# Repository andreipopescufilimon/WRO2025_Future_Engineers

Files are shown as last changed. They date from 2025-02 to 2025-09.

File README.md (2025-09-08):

# WRO2025 Future Engineers – Nerdvana Taurus Team

---

## WRO Open Championship 2025, Slovenia

At WRO Open 2025 in Slovenia, things started off really well for us. In the Open Round Challenge we managed to get full points in just 24 seconds, the fastest time there. Before that, in practice, the robot was running smoothly through all the tests and random cases we tried. At some point it had some strange speed drops, which we thought were from a bad cable connection. We resoldered everything, and from then on it worked perfectly again. Then came the real chaos. Just five minutes before the first official Obstacle Round, our motor driver chip blew up with a small spark. We tried to swap it out, but there just wasn’t enough time. The result: 0 points. Not exactly how we imagined the round going. That afternoon we stayed and worked on the robot, replacing the broken chip and all the resistors and capacitors around it. The next day, during the two hours of practice, the robot was back on track and almost hit full points again, but with small inconsistencies on the parking alignment. In the official run though, it made a small drift when doing the parking, and touched the parking wall, and because of the rules the whole parking didn’t count—not even partially. That was a bit painful, but in the end we still took 2nd place overall, and on documentation we scored 28 points. So yeah, it was a mix of highs and lows: fastest run of the round, a blown motor driver, afternoon repairs, and a nearly perfect comeback.

Thanks to HyperLine Robotics for sponsoring us! 

---

Repository of Nerdvana Taurus Team competing in the **World Robot Olympiad (WRO) 2025**, Future Engineers category. 

---

## 📚 Table of Contents

- [👥 The Team](#the-team)
- [🎯 Challenge Overview](#challenge-overview)
- [🤖 Our Robot](#our-robot)
- [⚙️ Mobility Management](#mobility-management)
  - [🚗 Drivebase](#drivebase)
    - [🔧 Drivetrain](#drivetrain)
    - [⚙️ Motor](#motor)
    - [🛞 Wheels](#wheels)
    - [🔌 Motor Driver IFX9201SG](#motor-driver)
    - [🌪️ Impeller](#impeller)
  - [🔄 Steering](#steering)
    - [🔄 Steering Servo Motor](#servo-motor)
  - [🏎️ Chassis & Component Mounting](#chassis)
    - [✨ Key Features & Advantages](#key-features)
    - [🔧 Assembly Process](#assembly-process)
      - [🔧 Assembly Process Video](#assembly-process-video)
      - [🔧 3D print the parts](#3d-print-the-parts)
      - [🔧 Assemble the robot](#assembly)
- [🛠️ Power and Sense Management](#power-and-sense-management)
  - [🔋 Li-Po Battery](#li-po-battery)
  - [🖥️ Arduino Nano ESP32](#arduino-nano-esp32)
  - [🧭 IMU Sensor BMI088](#imu-sensor-bmi088)
  - [📷 OpenMV H7 Camera](#openmv-h7-camera)
  - [⚙️ Drive Motor](#drive-motor)
  - [⚙️ Motor Driver IFX9201SG](#motor-driver)
  - [🔄 Steering Servo MG90S](#steering-servo)
  - [⚙️ Impeller](#impeller)
  - [📏 Pololu PWM Distance Sensor](#distance-sensors)
  - [🔌 Voltage Regulator D24V50F5](#voltage-regulator)
  - [🛠️ PCB Design](#pcb-design)
  - [⚡ Power Consumption](#power-consumption)
- [💻 Components coding](#components-coding)
  - [⚡ Drive motor](#drive-motor-coding)
  - [🌪️ Impeller](#impeller-coding)
  - [🎮 Servo motor](#servo-motor-coding)
  - [🧭 IMU](#imu-coding)
  - [📡 Distance sensors](#distance-sensors-coding)
  - [📷 Camera](#camera-coding)
- [📝 Obstacle Management](#obstacle-management)
  - [🏁 Open Round](#open-round) 
  - [⚡ Final Round](#final-round)
  - [🅿️ Start from Parking](#start-from-parking)
  - [🅿️ Parking](#parking)
- [📽️ Performance Video](#performance-video)
- [💰 Cost Analysis](#cost-analysis)
  - [📦 Component Costs](#components-costs)
  - [🔌 PCB Manufacturing Cost](#pcb-cost)
  - [🖨️ 3D Printing Cost](#3d-printing-cost)
  - [🔩 Other Materials (Screws, Nuts, Miscellaneous)](#other-materials-cost)
  - [💵 Total Cost](#total-cost)
- [📂 Resources](#resources)
- [📜 License](#license)

## 📂 Folder Structure

This repository is organized as follows:

```
📦 WRO2025_Future_Engineers
├── 📁 3D-models             # Contains 3D design files for the robot's components
│   ├── 📁 old-3D-models     # Previous versions of 3D models
│   └── 📁 step-models       # 3D models in STEP format
├── 📁 electrical-schematics # Circuit diagrams and wiring
├── 📁 github-commits        # Commit logs and change tracking details for this repository
├── 📁 media                 # Images and videos 
│   ├── 📁 robot-photos      # Photos of the robot
│   ├── 📁 team-photos       # Pictures of team members and teamwork
│   └── 📁 video             # Recorded testing
├── 📁 other                 # Contains files that do not fit into other categories
├── 📁 src                   # Main source code for the robot
├── 📁 technical-draws       # Technical drawings and mechanical blueprints
├── 📁 video                 # Videos of our robot
├── 📄 LICENSE               # MIT License for the project
└── 📄 README.md             # Main documentation for the project
```

---

## 👥 The Team 

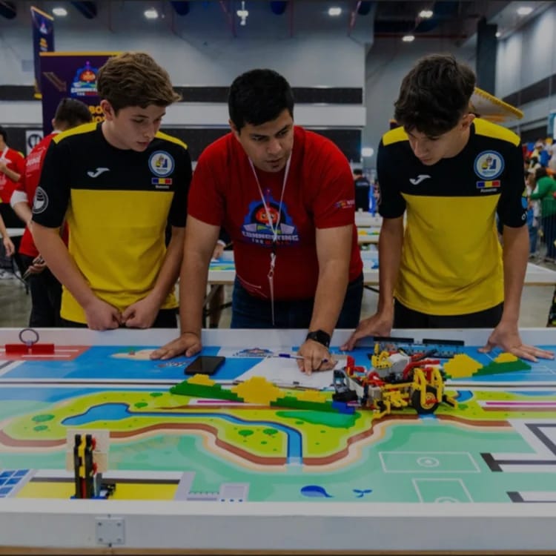
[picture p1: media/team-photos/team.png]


**This image was taken at the **WRO 2023 International Final** in Panama, where we placed **14th in the Robomission Junior Category**.*

### **Popescu Filimon Andrei Cosmin** (Left Side)
**Age:** 17 <br>

**High School:** International Computer High School Bucharest (ICHB)  

**Description:**  
Hi! I’m Andrei from Romania, and this is my fifth WRO season. This is my first season in Future Engineers, as before I competed in Robomission category. I am passionate about robotics especially electronics and latest algorithms and tech. Over the years, I have worked on multiple robotics projects, including line followers, sumo bots, and air quality modules. Apart from robotics, I also enjoy cybersecurity, programming, and cycling.

---

### **Horia Simion** (Right Side)
**Age:** 16 <br>
**High School:** National College "Mihai Viteazul" (CNMV)

**Description:**  
Hi! I’m Horia from Romania, and this is my second WRO season competing alongside Andrei. I have participated in RoboMission multiple times, gaining valuable experience in solving various problems that may arise while building a robot. I have a strong interest in technology and robotics and am always eager to learn and experiment with new ideas.

---

## 🎯 Challenge Overview 

The **WRO 2025 Future Engineers** challenge pushes teams to develop a **fully autonomous vehicle** capable of navigating a **dynamic and randomized racetrack** using **sensors, computer vision, and advanced control algorithms**. The goal is to complete **multiple laps** while adapting to randomized obstacles, following **strict driving rules**, and successfully executing a **parallel parking maneuver** at the end of the course.

### 📌 Competition Format 

- **🏁 Open Challenge**: The vehicle must complete **three (3) laps** on a track with **randomly placed inside walls**.

- **🚦 Obstacle Challenge**: The vehicle must complete **three (3) laps** while detecting and responding to **randomly placed red and green traffic signs**:
  - 🟥 **Red markers** ➜ The vehicle must stay on the **right side of the lane**.
  - 🟩 **Green markers** ➜ The vehicle must stay on the **left side of the lane**.
  
  After completing the three laps, the vehicle must **locate the designated parking zone** and perform a **precise parallel parking maneuver** within a limited space, adding an extra layer of difficulty.
  
- **📑 Documentation**: Each team must maintain a **public GitHub repository** showcasing their **engineering process, vehicle design, and source code**.

### 🏆 Scoring & Evaluation
Scoring is based on **accuracy, technical documentation and speed**, rewarding teams that balance **efficiency, adaptability, and innovation**. This challenge not only tests **robotics and programming skills** but also promotes **problem-solving, teamwork, and engineering creativity**.

🔗 **Find out more about the challenge [here](https://wro-association.org/wp-content/uploads/WRO-2025-Future-Engineers-Self-Driving-Cars-General-Rules.pdf).** 🚀

---

## 🤖 Our Robot 
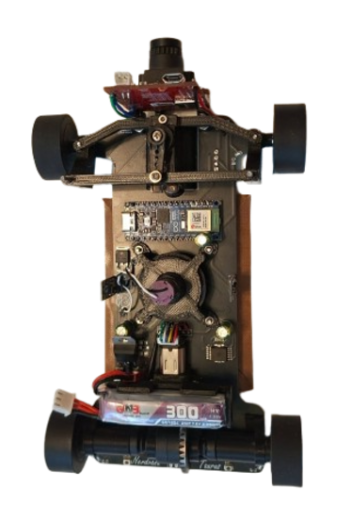
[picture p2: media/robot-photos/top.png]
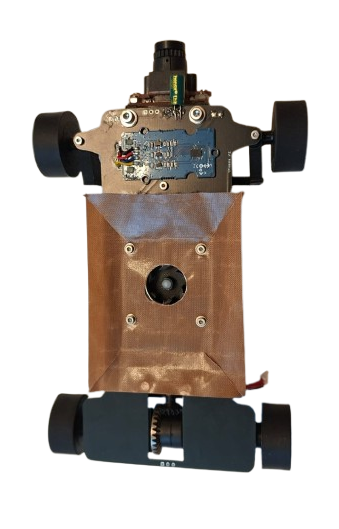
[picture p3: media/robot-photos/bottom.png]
|  |  |
|---|---|
| <p align="center"><b>Top</b></p> | <p align="center"><b>Bottom</b></p> |

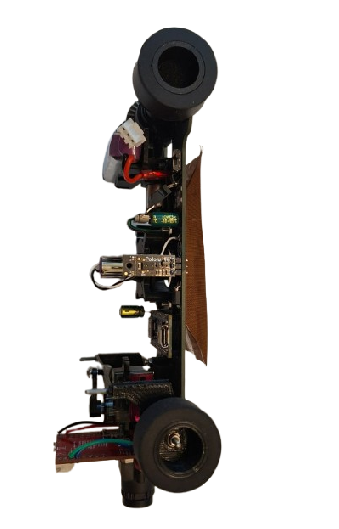
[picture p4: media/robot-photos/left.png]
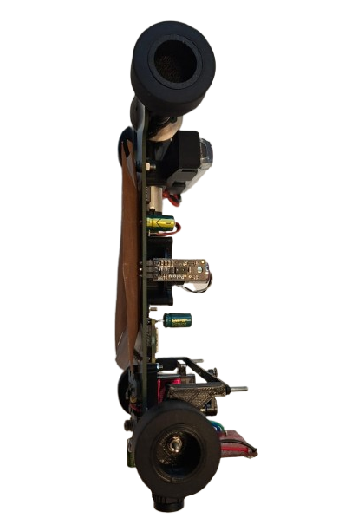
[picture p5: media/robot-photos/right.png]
|  |  |
|---|---|
| <p align="center"><b>Left</b></p> | <p align="center"><b>Right</b></p> |

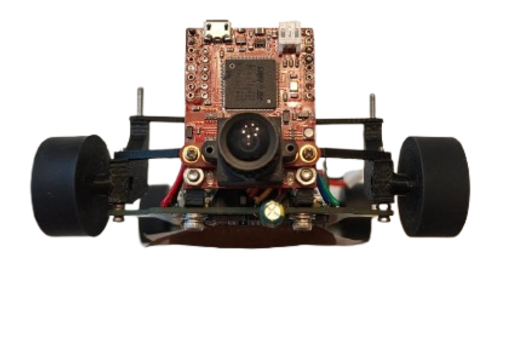
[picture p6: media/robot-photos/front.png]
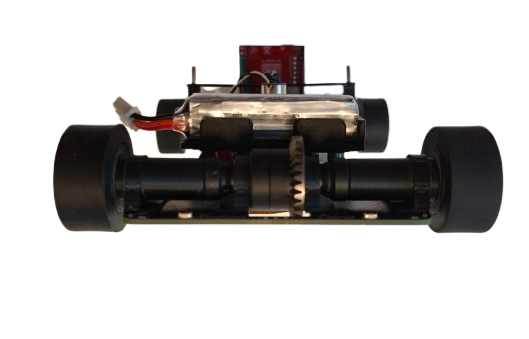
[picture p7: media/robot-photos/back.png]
|  |  |
|---|---|
| <p align="center"><b>Front</b></p> | <p align="center"><b>Back</b></p> |

---

## 🚗 Mobility Management 

The robot's mobility is controlled through **a fully PCB chassis, a servo-based steering system, and a drivetrain featuring a RC differential and axes**. These components work together to ensure smooth, **precise movement with optimized traction, stability, and efficient power management**.

## ⚙️ **Drivebase** 

### 🔧 **Drivetrain** 

The drivetrain uses a sealed RC differential at the rear, driven by a **Pololu 30:1 HPCB micro gearmotor** through a **3D printed pinion** → **differential input gear**. The motor is held in a 3D-printed support with the battery mounted above, keeping the center of mass centered and low. Rear outputs rotate in bearings seated inside 4 printed rings that are super-glued to the PCB chassis, minimizing friction and parts count.
At the front, the wheels are fully 3D-printed and each wheel runs on two bearings (inner + outer) for a rigid, wobble-free hub that steers precisely.

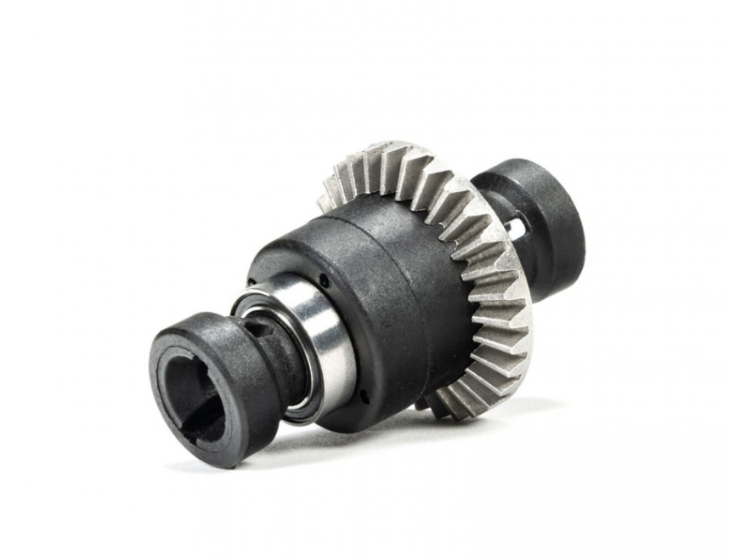
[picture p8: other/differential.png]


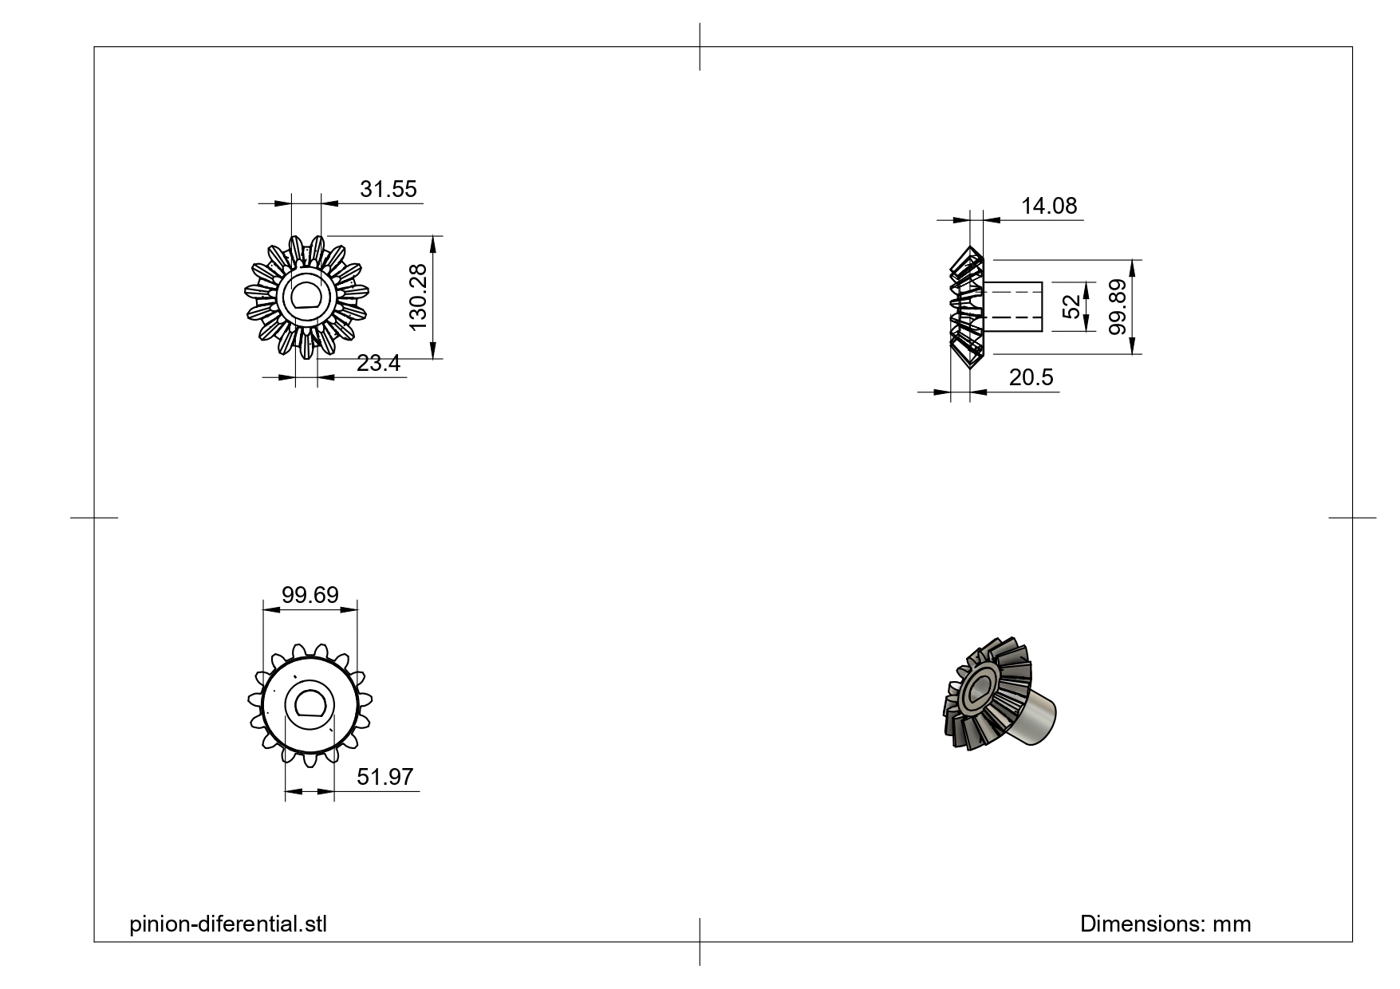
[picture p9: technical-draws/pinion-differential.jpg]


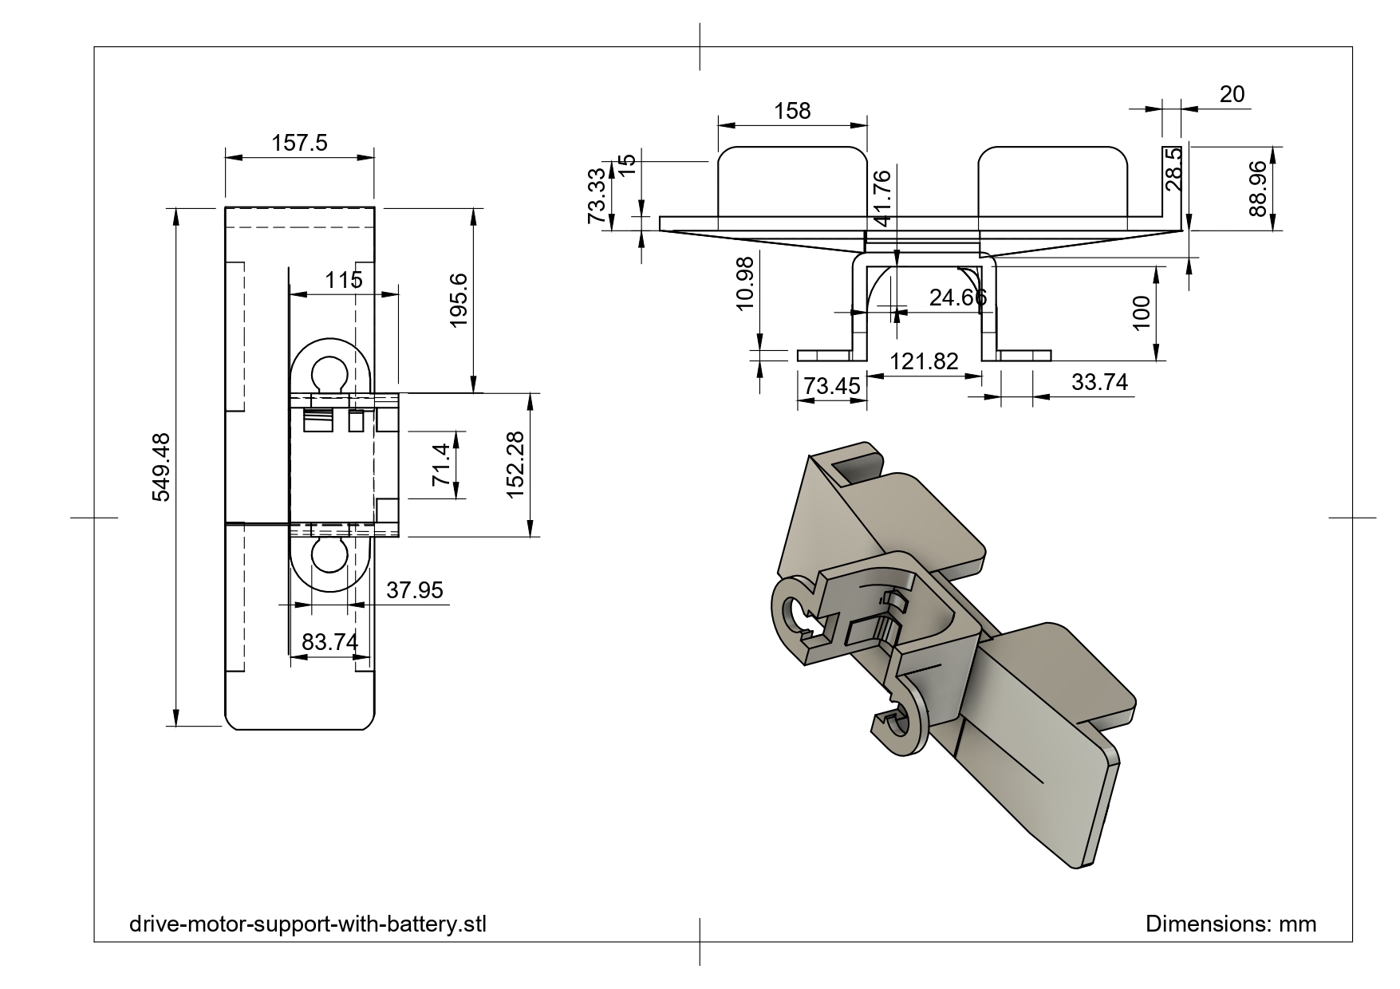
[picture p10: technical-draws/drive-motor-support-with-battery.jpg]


To maximize grip on the track without adding mass, we use a **downforce impeller (1020 coreless motor)** that pulls air from under the robot, increasing the normal force. The impeller is PWM-controlled via an **RFR3411 MOSFET (low-side switch)**. The drive motor is controlled by an **IFX9201SG driver (PWM + DIR)** with an active brake pulse for precise stopping, while the encoder on the gearmotor provides odometry for short, accurate moves (e.g., avoidance hops, parking nudges).

### ⚙️ **Motor – 30:1 Micro Metal Pololu Gearmotor HPCB** 
Following past testing, we selected **a high-power 30:1 Micro Metal Gearmotor (12V)** for the drive system. This motor provides an **optimal balance of speed and torque**, allowing the robot to maintain stability while navigating turns.

|  | **Specifications** |
|---|---|
| **Model:** 30:1 HPCB | **Voltage:** 6V |
| **No-load Speed:** 1000 RPM | **No-load Current:** 120mA |
| **Stall Torque:** ~0.4 kg·cm | **Stall Current:** 1.6A |
| 🔗 **[Buy Here](https://www.pololu.com/product/3038)** | **Function:** Drives the robot |

**Why We Chose This Motor?**  
**- Gear ratio provides suffi cient torque** without sacrificing efficiency.  
**- Compact and lightweight design**, allowing integration into a lightweight robot.  

### 🛞 Wheels & Tires (Silicone) 

Our robot uses cast silicone tires on 3D-printed hubs. Silicone provides high, repeatable static friction on painted boards and vinyl, which pairs perfectly with the rear differential and downforce impeller—more grip when we need it, without adding mass.

**Why silicone?**
- Grip & consistency: Strong adhesion on smooth surfaces → faster exits and shorter braking distances.
- Low wear on the map: Softer compound grips without scratching.
- Stable handling: Predictable breakaway, so PD/PID steering stays smooth.

**Construction:**
- Rims: 3D-printed hubs with dual bearings (inner + outer) for a rigid, wobble-free wheel.
- Tire: Cast silicone ring fitted onto a mechanical bead on the rim (no harsh solvents needed).
- Fit: Rear wheels mount directly to the diff outputs; fronts ride on steering hubs for low friction.

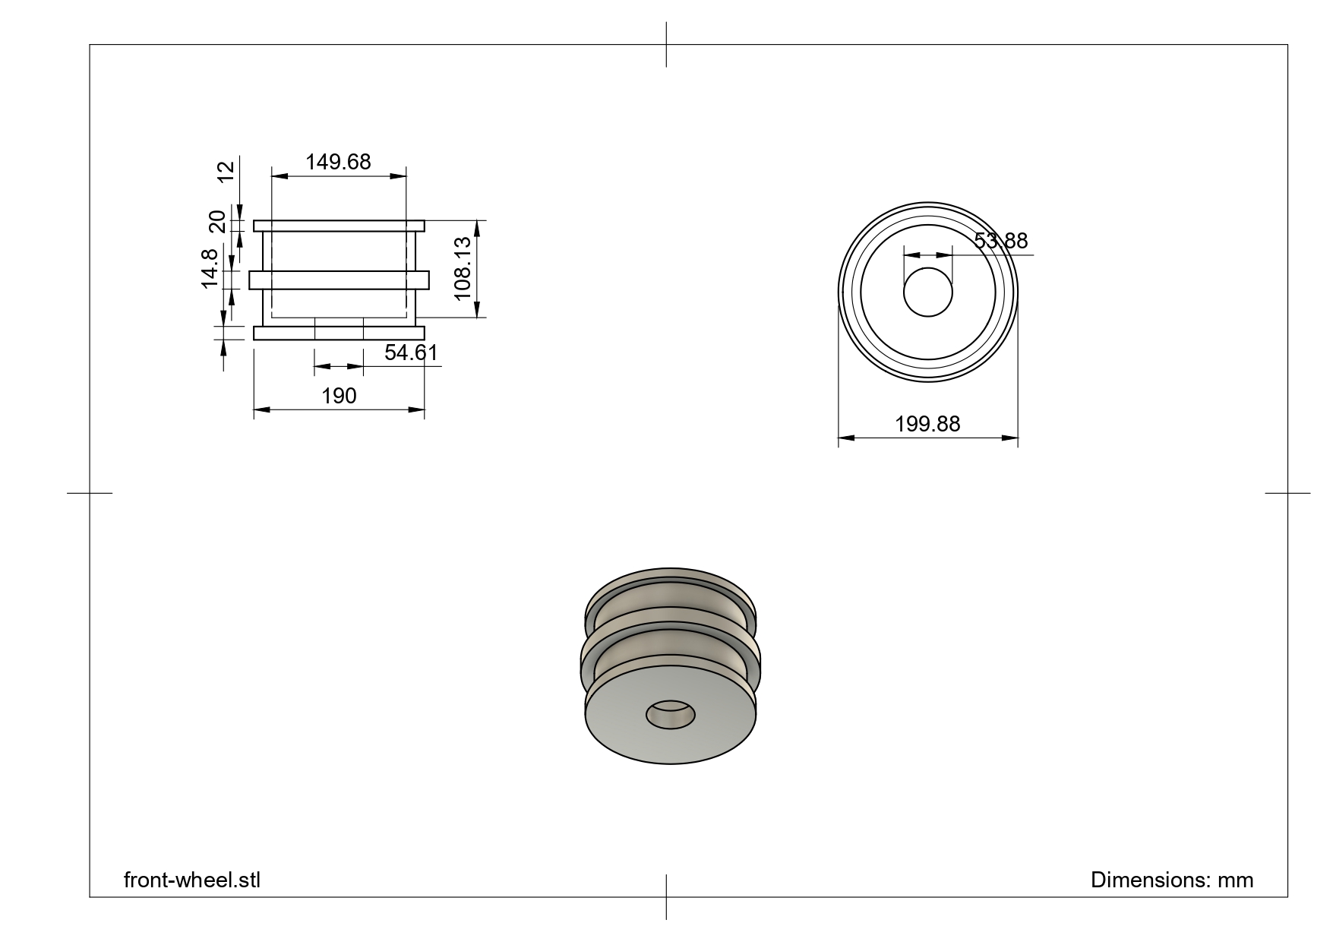
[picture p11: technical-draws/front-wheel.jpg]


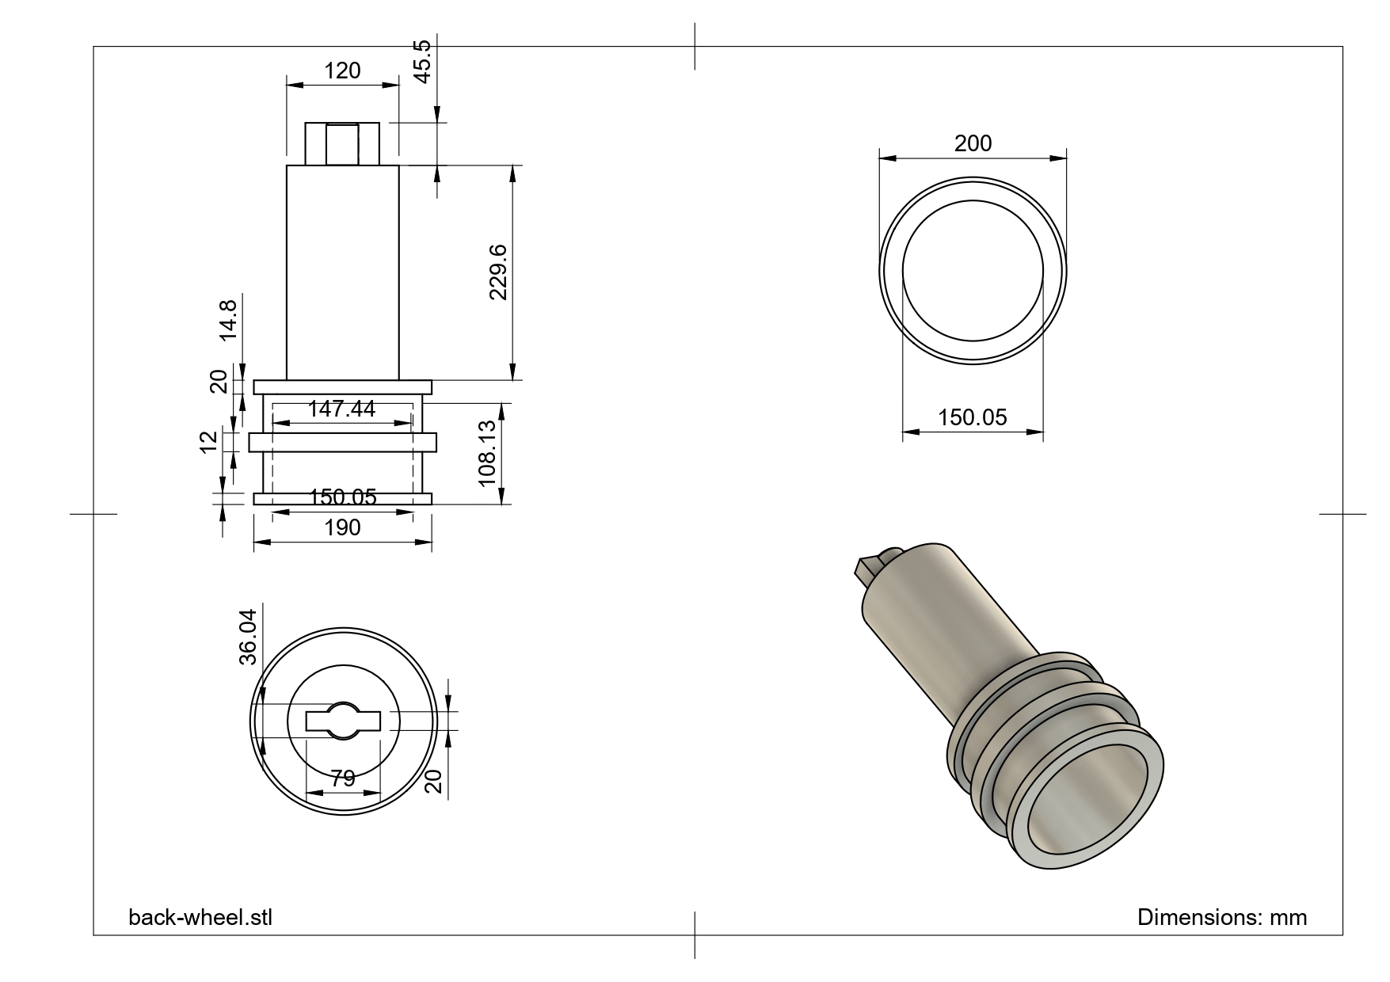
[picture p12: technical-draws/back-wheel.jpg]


### 🔌 **IFX9201SG Motor Driver** 

The **IFX9201SG** motor driver is used to control the robot’s high-performance drive or impeller motor with precision and efficiency. It supports PWM-based speed control and direction control while integrating advanced protection features, making it ideal for demanding robotics applications. The IFX9201SG is directly integrated into our PCB, ensuring compact design and reliable communication with the Arduino Nano ESP32.

|  | **Specifications** |
|---|---|
| **Model:** IFX9201SG | **Operating Voltage:** 5.5V – 45V |
| **Logic Voltage:** 3.3V / 5V compatible | **PWM Frequency:** Up to 20 kHz |
| **Max Continuous Current:** 5A | **Max Peak Current:** 8A per channel |
| **Control Interface:** PWM + Direction pins | **Built-in Protections:** Overtemperature, Overcurrent, Undervoltage, Short-to-GND/Battery |
| 🔗 **[Buy Here](https://www.lcsc.com/product-image/C112633.html)** | **Function:** Controls drive motors |

### **⚙️ Impeller for downforce** <a id="impeller">

The **impeller** generates downforce to improve the robot’s grip on the track at high speeds. Powered by a **1020 coreless DC motor**, it delivers extremely high RPM with minimal weight, making it ideal for competitive line follower and robotracer builds. Its low rotor inertia ensures instant acceleration, while the compact size allows for easy integration.

|  | **Specifications** |
|---|---|
| **Type:** Coreless DC Motor | **Model:** 1020 |
| **Voltage:** 3.7–7.4V | **Shaft Diameter:** 1.0mm |
| **No-Load Speed:** ~53,000 RPM @ 3.7V	 | **	Weight:** ~4.5g |
| **Current Draw (Avg):** ~1A @ 3.7V	 | **Peak Current:** ~2.5A |
| 🔗 **[Buy Here](https://hyperlinerobotics.com/products/impeller.html)** | **Function:** Drives the downforce impeller |

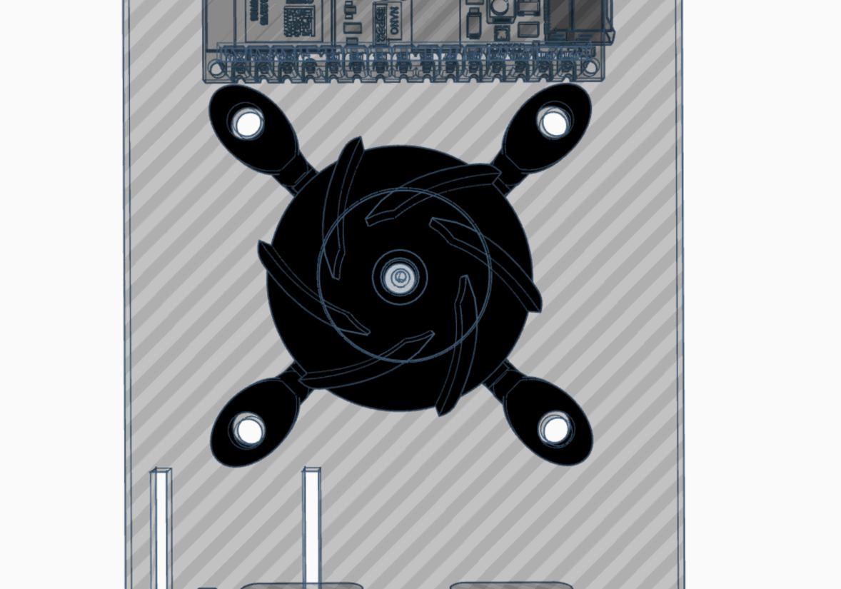
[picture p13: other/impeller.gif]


---

## 🔄 **Steering** 

The **steering system** is a critical part of the robot, ensuring precise maneuverability and smooth turns. Our design is based on a **parallelogram steering mechanism**, where both front wheels turn at the same angle through a single servo-controlled linkage. This setup provides predictable and stable steering, making it easy to use for an autonomous vehicle. Instead of using an **Ackermann steering system**, which requires more complex calculations and linkages, we opted for a **simpler and more lightweight solution** that offers consistent control. Our steering system allows for a maximum turning angle of 80 degrees in both the left and right directions. This range provides precise maneuverability, enabling the robot to navigate sharp turns efficiently while maintaining stability.

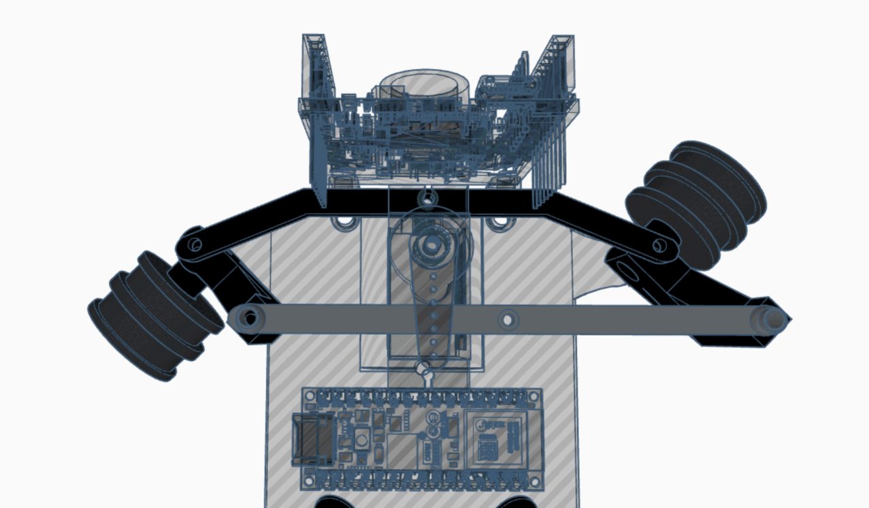
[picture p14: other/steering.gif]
Demo GIF


Our **steering arm is directly connected to the servo**, which moves the two front wheels simultaneously. This ensures that the turning response is immediate and proportional to the servo's motion. The **wheels are mounted on special mounts hubs**, allowing for smooth and precise movement without excessive friction. To ensure **structural integrity and long-term reliability**, the steering system is **assembled using 2 M2 screws on which the hubs can turn**. 

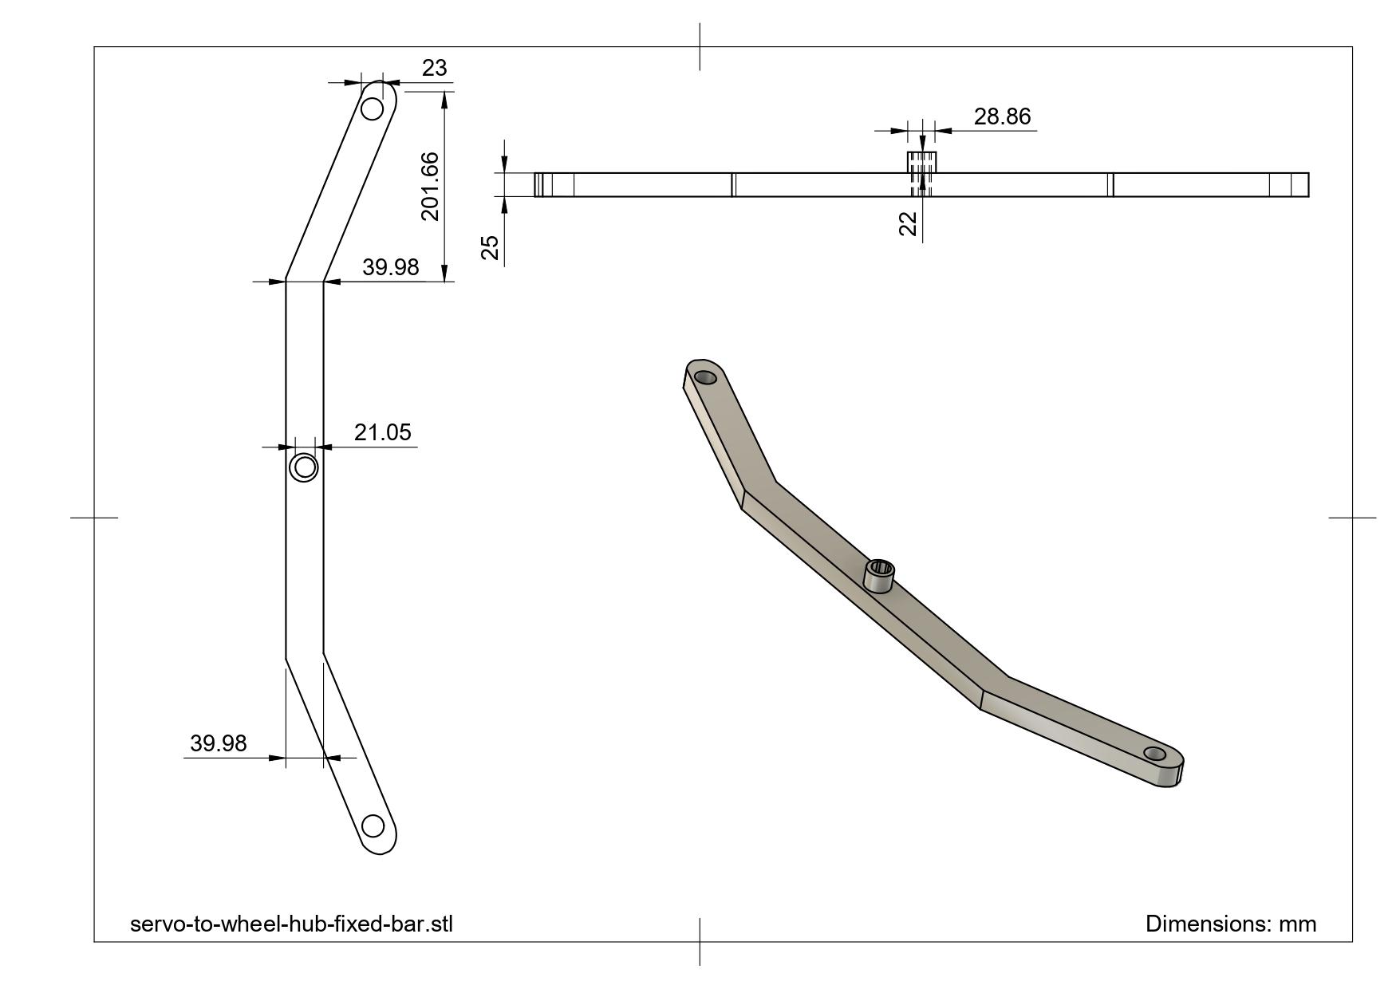
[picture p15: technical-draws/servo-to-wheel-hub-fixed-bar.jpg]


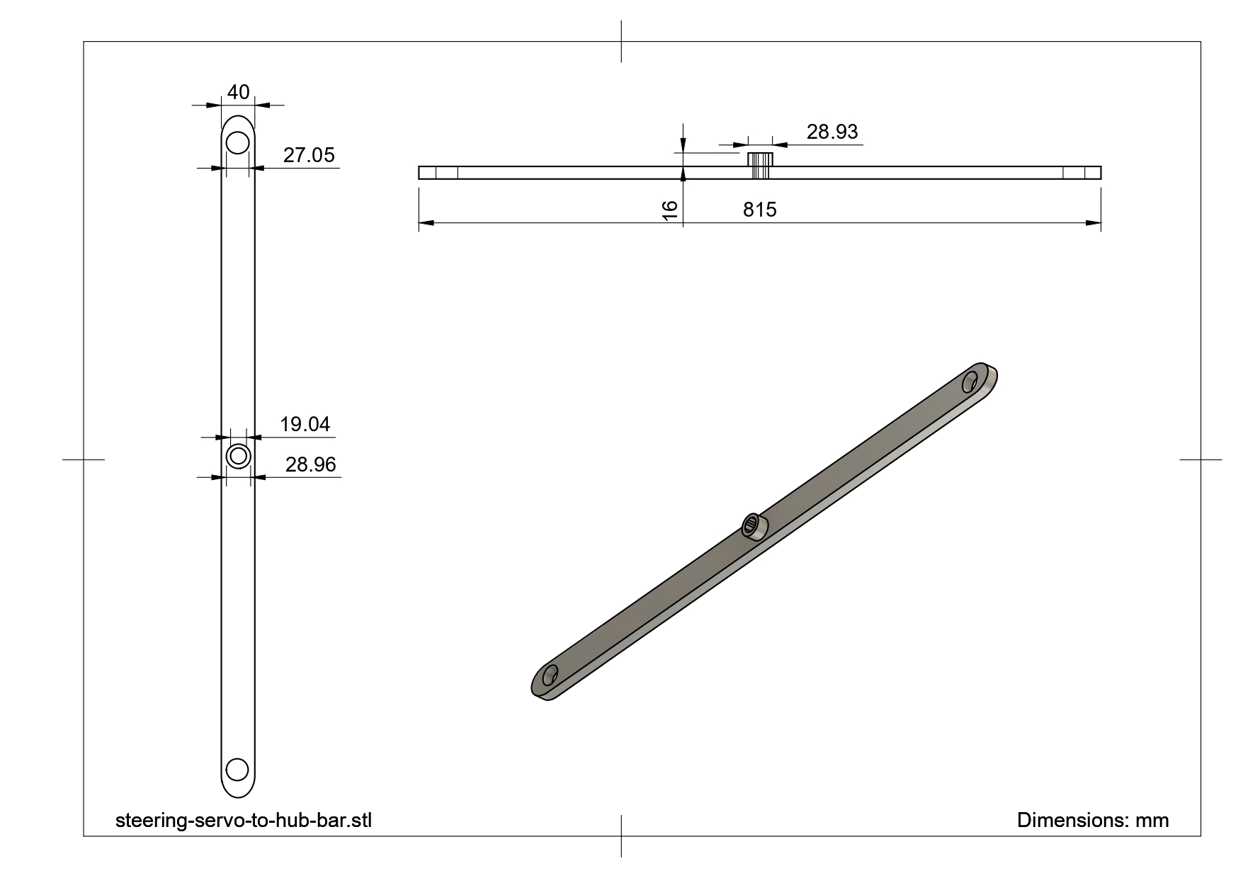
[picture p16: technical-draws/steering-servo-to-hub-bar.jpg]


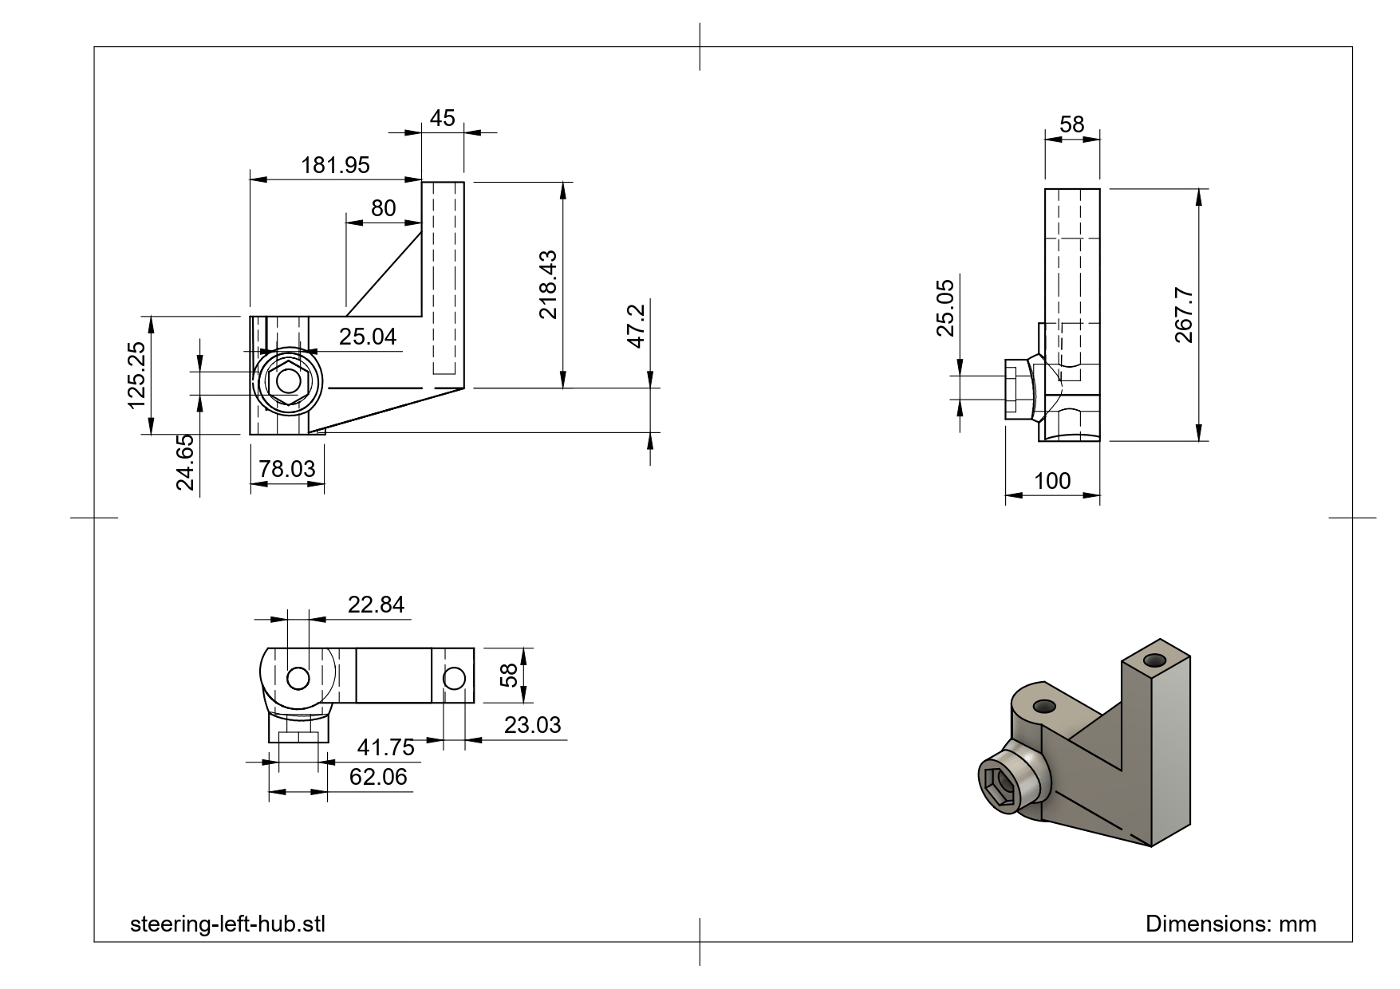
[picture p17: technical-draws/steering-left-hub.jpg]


**⚙️ Design Considerations & Improvements** <br>
While the parallelogram steering system is effective, some potential enhancements could improve its performance. Additionally, optimizing the **motor mounts** could reduce mechanical play, making the system more precise. In future iterations, we may experiment with **Ackermann geometry** and suspension to better distribute wheel angles during turns, further improving efficiency and reducing tire slippage.

---

### **🔄 Steering Servo – MG90S** 

To control the steering system, we use an **MG90S micro servo**, known for its high torque and fast response. This servo enables quick and precise adjustments while maintaining a compact and lightweight design. Featuring **metal gears**, it ensures durability and reliability over extended use. The servo is securely mounted onto the chassis with two screws, and the steering arm is directly attached to its output shaft, providing smooth and efficient motion transfer for accurate steering.

|  | **Specifications** |
|---|---|
| **Model:** MG90S | **Voltage:** 5V |
| **Torque:** 2.2kg/cm | **Signal Type:** PWM |
| **Current Draw (Avg):** 120mA | **Peak Current:** 500mA |
| **Weight:** ~13.4g | **Gears:** Plastic |
| 🔗 **[Buy Here](https://www.optimusdigital.ro/ro/motoare-servomotoare/271-servomotor-mg90s.html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)** | **Function:** Controls steering |

---

## 🏎️ **Chassis & Component Mounting** 

At the national stage, we used a **fully 3D-printed chassis**, which allowed us to quickly prototype a compact and optimized structure. However, for the current version, we upgraded to a **PCB-based chassis**. This not only reduces weight further but also integrates electronics directly into the structure, making the robot lighter, cleaner, and more reliable.

The robot is driven by **a single high-performance motor**, which is connected to a **professional RC differential**. This setup allows reducing complexity while maintaining precise control over movement.

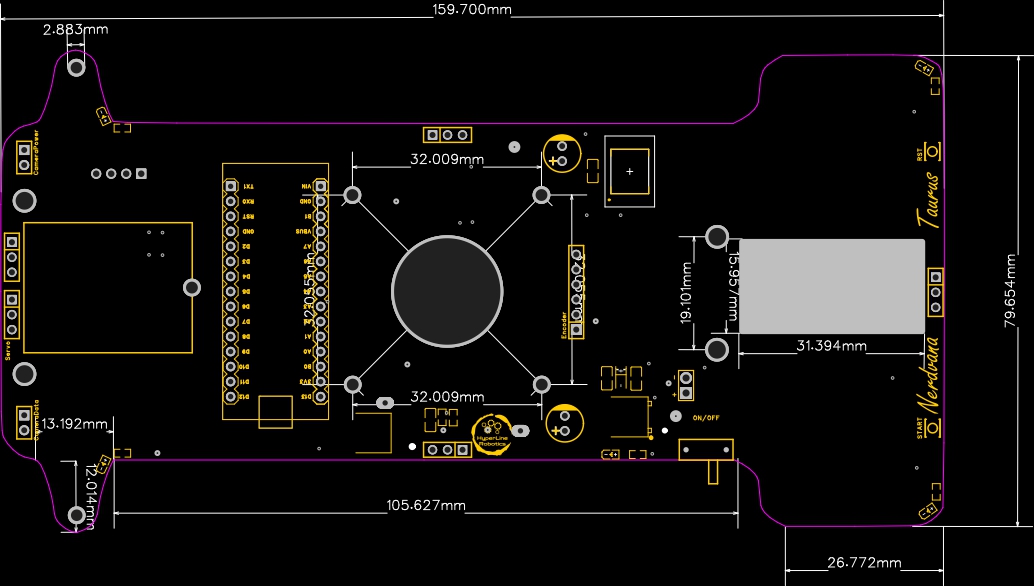
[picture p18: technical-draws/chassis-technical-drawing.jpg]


**Key Features & Advantages** 

➜ **Lightweight & Durable** – The **PCB chassis** ensures a strong lightweight structure, optimizing performance.  
➜ **Balanced Design** – The **battery is centrally placed on top of the motor**, ensuring even weight distribution and stability. Meanwhile we use a high power impeller that sucks the air under the robot and create an artificial downforce effect over the robot maintaining its grip.  
➜ **Easy Component Mounting** – Pre-designed slots for **motor, steering servo, and camera** make assembly quick and efficient.  
➜ **Organized Wiring & Cable Management**  
&nbsp; &nbsp; 🔹 **Integrated PCB routing** eliminates unnecessary wiring, ensuring a cleaner and more reliable setup.  
&nbsp; &nbsp; 🔹 **Super glue secures servo and other tiny parts**, keeping each part in its place even after longer runs. 

---

## 🔧 Assembly Process 

🔗 **[Click here to watch the assembly video on YouTube](https://youtu.be/sC2x8HgDEvk)** 

### 1: 3D Print the Parts 

The 3D model files are available in the [`/3D-models`](https://github.com/andreipopescufilimon/WRO2025_Future_Engineers/tree/main/3D-models) folder. We used a **BambuLab X1-Carbon**, but any good quality printer will work.

Printed components include:

* **Servo base** – for securing the MG90S steering servo.
* **Camera mount (90° bracket)** – to hold the camera in position.
* **Motor support** – for fixing the drive motor with M3 screws.
* **Bearing rings** – 4 small rings to be glued on the PCB chassis for smooth differential rotation.
* **Front wheels** – fully 3D-printed, each equipped with **2 bearings (inner + outer)** for stable and secured placement.

---

### 2: Assemble the Chassis & Components 

The final robot is built on a **custom PCB chassis**, manufactured by **JLCPCB**, which acts as both the **structural base** and the **mainboard for electronics**.

#### 🔧 **Main Assembly Steps**

1. **PCB Preparation**

   * Order the chassis PCB from **JLCPCB**.
   * Solder the **Arduino Nano ESP32** into its slot.
   * Solder the **4 distance sensors** with **90° male pins**, positioned on all four sides of the robot.

2. **Steering System**

   * Mount the **MG90S servo** on the **3D-printed base**, then super glue the base securely to the PCB chassis.
   * Fix the **steering hubs** (left & right) on **M2 screws**, allowing smooth wheel hub rotation.
   * Connect the **servo arm to the steering hubs** using **two metal link bars** for precise steering.
   * Install the **3D-printed front wheels**, each fitted with **dual bearings (inner + outer)** for reliable and stable rotation.

3. **Camera Mounting**

   * Attach the camera using the **90° 3D-printed bracket**.
   * Secure it with **2 screws to the chassis** and **2 screws for the camera itself**.

4. **Motor & Drivetrain**

   * Place the **drive motor** on the **3D-printed support**, fixed with **2 × M3 screws**.
   * Secure the **impeller** with **4 screws** to its mounting position.
   * Assemble the **RC differential** with the rear wheels mounts that directly fit the differential left and right mounting holes.
   * Glue **4 printed rings** on the PCB chassis to house bearings, ensuring **smooth rear wheel rotation**.

5. **Wiring & Final Connections**

   * Solder all cables (servo, camera, motor encoder, impeller) to their designated pads on the PCB.
   * Use minimal hot glue to fix loose wires and prevent interference during movement.

---

## 🛠️ Power and Sense Management 

The robot's **power and sensing system** is designed for **efficiency, precision, and adaptability**. It consists of an **Arduino Nano ESP32, a Li-Po battery, BMI088 IMU, OpenMV H7 Camera, motors(drive motor and servo motor), and a voltage regulator**, all working together to ensure **stable operation and accurate navigation**.  

Each component has been carefully selected to provide **optimal performance**, minimize power consumption, and ensure **reliability in competition environments**.

---

### **🔋 Li-Po Battery – 2S 300mAh** 

The **Li-Po battery** provides a **compact, lightweight, and high-discharge** power source, making it ideal for our robot. The **7.4V output** is suitable for running our **motors and voltage regulator**, ensuring stable power delivery.

|  | **Specifications** |
|---|---|
| **Model:** 2S Li-Po | **Capacity:** 300mAh |
| **Voltage:** 7.4V | **Discharge Rate:** 60C |
| **Weight:** 12g | **Size:** 13.8 x 12 x 52.5mm |
| **Output Current:** Varies by load | **Connector Type:** JST |
| 🔗 **[Buy Here](https://www.jsumo.com/jsumo-3s-111-volt-450-mah-lipo-battery)** | **Function:** Powers the entire robot |

---

### **🖥️ Arduino Nano ESP32 – Main Controller** <a id="arduino-nano-esp32">

The **Arduino Nano ESP32** provides **high-speed processing, built-in Wi-Fi and Bluetooth, and extensive GPIO capabilities** in a **compact form**. This allows it to handle **sensor data, motor control, and vision processing efficiently**.

|  | **Specifications** |
|---|---|
| **Microcontroller:** ESP32 | **Flash Memory:** 4MB |
| **SRAM:** 520KB | **Frequency:** 240MHz |
| **Pins:** 22 | **Input Voltage:** 5V |
| **Current Draw (Avg):** 200mA | **Peak Current:** 500mA |
| 🔗 **[Buy Here](https://store.arduino.cc/en-ro/products/nano-esp32)** | **Function:** Controls all robot components |

---

### 🧭 IMU Sensor – BMI088 

The **BMI088 IMU** is used to **measure the robot's angular velocity and acceleration**, helping it maintain **stability and precise movement control**. It is essential for **calculating turns and avoiding drift**.

|  | **Specifications** |
|---|---|
| **Gyroscope Range:** ±2000°/s | **Accelerometer Range:** ±24g |
| **Interface:** I2C / SPI | **Supply Voltage:** 3.0V – 3.6V |
| **Current Draw:** ~3.2mA | **Weight:** ~1g |
| 🔗 [Buy Here](https://wiki.seeedstudio.com/Grove-6-Axis_Accelerometer&Gyroscope_BMI088/) | **Function:** Tracks orientation & motion |

---

### **📷 OpenMV H7 Camera – Vision Processing** <a id="openmv-h7-camera">

The **OpenMV H7 Camera** processes **traffic signs, lane detection, and other visual cues** in real-time. Unlike traditional cameras, it has a **built-in microcontroller**, reducing the processing load on the Arduino and allowing it to **focus on movement control**.

|  | **Specifications** |
|---|---|
| **Microcontroller:** STM32H7 | **Flash Memory:** 32MB |
| **RAM:** 512KB | **Frequency:** 480MHz |
| **Resolution:** 640x480 | **Frame Rate:** 60fps |
| **Current Draw (Avg):** 300mA | **Peak Current:** 400mA |
| 🔗 **[Buy Here](https://openmv.io/products/openmv-cam-h7)** | **Function:** Detects traffic signs & lanes |

---

### **⚙️ Drive Motor – 30:1 Micro Metal Gearmotor HPCB 6V w/ Encoder** <a id="drive-motor">

The **drive motor is responsible for propelling the robot forward**. The **30:1 gearbox** provides an excellent **balance of speed and torque**, while the **built-in encoder** allows for **precise speed control**.

|  | **Specifications** |
|---|---|
| **Type:** Micro Metal Gearmotor | **Gear Ratio:** 30:1 |
| **Voltage:** 6V | **Encoder:** Yes |
| **Current Draw (Avg):** 120mA | **Peak Current:** 1.6A |
| **Weight:** ~10g | **Shaft Diameter:** 3mm |
| 🔗 **[Buy Here](https://www.pololu.com/product/3038)** | **Function:** Drives the robot |

---

### **⚙️ IFX9201SG Motor Driver** 

The **IFX9201SG** motor driver is used to control the robot’s high-performance drive or impeller motor with precision and efficiency. It supports PWM-based speed control and direction control while integrating advanced protection features, making it ideal for demanding robotics applications. The IFX9201SG is directly integrated into our PCB, ensuring compact design and reliable communication with the Arduino Nano ESP32.

|  | **Specifications** |
|---|---|
| **Model:** IFX9201SG | **Operating Voltage:** 5.5V – 45V |
| **Logic Voltage:** 3.3V / 5V compatible | **PWM Frequency:** Up to 20 kHz |
| **Max Continuous Current:** 5A | **Max Peak Current:** 8A per channel |
| **Control Interface:** PWM + Direction pins | **Built-in Protections:** Overtemperature, Overcurrent, Undervoltage, Short-to-GND/Battery |
| 🔗 **[Buy Here](https://www.lcsc.com/product-image/C112633.html)** | **Function:** Controls drive motors |

---

### **🔄 Steering Servo – MG90S** <a id="steering-servo">

The **MG90S servo is used for precise steering control**, enabling the robot to **navigate turns with accuracy**. It provides **high torque output in a compact size**.

|  | **Specifications** |
|---|---|
| **Model:** MG90S | **Voltage:** 5V |
| **Torque:** 2.2kg/cm | **Signal Type:** PWM |
| **Current Draw (Avg):** 120mA | **Peak Current:** 500mA |
| **Weight:** ~13.4g | **Gears:** Plastic |
| 🔗 **[Buy Here](https://www.optimusdigital.ro/ro/motoare-servomotoare/271-servomotor-mg90s.html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)** | **Function:** Controls steering |

---

### **⚙️ Impeller for downforce** <a id="impeller">

The **impeller** generates downforce to improve the robot’s grip on the track at high speeds. Powered by a **1020 coreless DC motor**, it delivers extremely high RPM with minimal weight, making it ideal for competitive line follower and robotracer builds. Its low rotor inertia ensures instant acceleration, while the compact size allows for easy integration.

|  | **Specifications** |
|---|---|
| **Type:** Coreless DC Motor | **Model:** 1020 |
| **Voltage:** 3.7–7.4V | **Shaft Diameter:** 1.0mm |
| **No-Load Speed:** ~53,000 RPM @ 3.7V	 | **	Weight:** ~4.5g |
| **Current Draw (Avg):** ~1A @ 3.7V	 | **Peak Current:** ~2.5A |
| 🔗 **[Buy Here](https://hyperlinerobotics.com/products/impeller.html)** | **Function:** Drives the downforce impeller |



---

### 📏 Distance Sensor – Pololu PWM Distance Sensor 

The **Pololu Digital Distance Sensor (PW output, 50 cm max)** uses a short-range lidar module and reports distance as the width of a digital pulse (similar to a hobby-servo signal). It’s ideal for reliable, fast obstacle detection and gives you an actual distance reading (3 mm resolution), perfect for lap direction detection at start and for close-range wall sensing.

|  | **Specifications** |
|---|---|
| **Detection Range:** 50 cm (depends on surface) | **Type:** Digital pulse width (HIGH-time encodes distance) |
| **Voltage Supply:** 3.0V – 5.5V | **Current Draw:** ~30 mA enabled, ~0.4 mA disabled (EN low) |
| **Resolution:** 3 mm (≈ 4 µs per 3 mm)	 | **Update Rate:** ~50–110 Hz (period ~20–9 ms) |
| **Dimensions:** 21.6mm × 8.9mm × 3.1mm | **Weight:** 1g |
| 🔗 [Buy Here](https://www.pololu.com/product/4064) | **Use Case:** Start-line lap direction & close-range obstacle sensing for parking |

---

### **🔌 D24V50F5 Voltage Regulator – Power Management** <a id="voltage-regulator"> 

The **D24V50F5** regulates the **11.1V Li-Po battery output** to a **stable 5V**, ensuring **safe power delivery** to the **Arduino, sensors, and camera**. It prevents **overvoltage damage** and includes **thermal & short-circuit protection** for reliability.

|   | **Specifications** |
|---|---|
| **Model:** D24V50F5 | **Input Voltage:** 6V – 38V |
| **Output Voltage:** 5V | **Output Current:** 5A |
| **Efficiency:** Linear Regulator | **Dropout Voltage:** ~2V |
| **Protection:** Short-circuit & thermal shutdown | **Mounting Type:** Pins |
| 🔗 **[Buy Here](https://www.pololu.com/product/2851)** | **Function:** Converts battery voltage to 5V |

---

### **🛠️ PCB Design** 
| **Electrical Schematics** | **PCB Design Cooper Traces** | **Chassis after Production** |
|---|---|---|
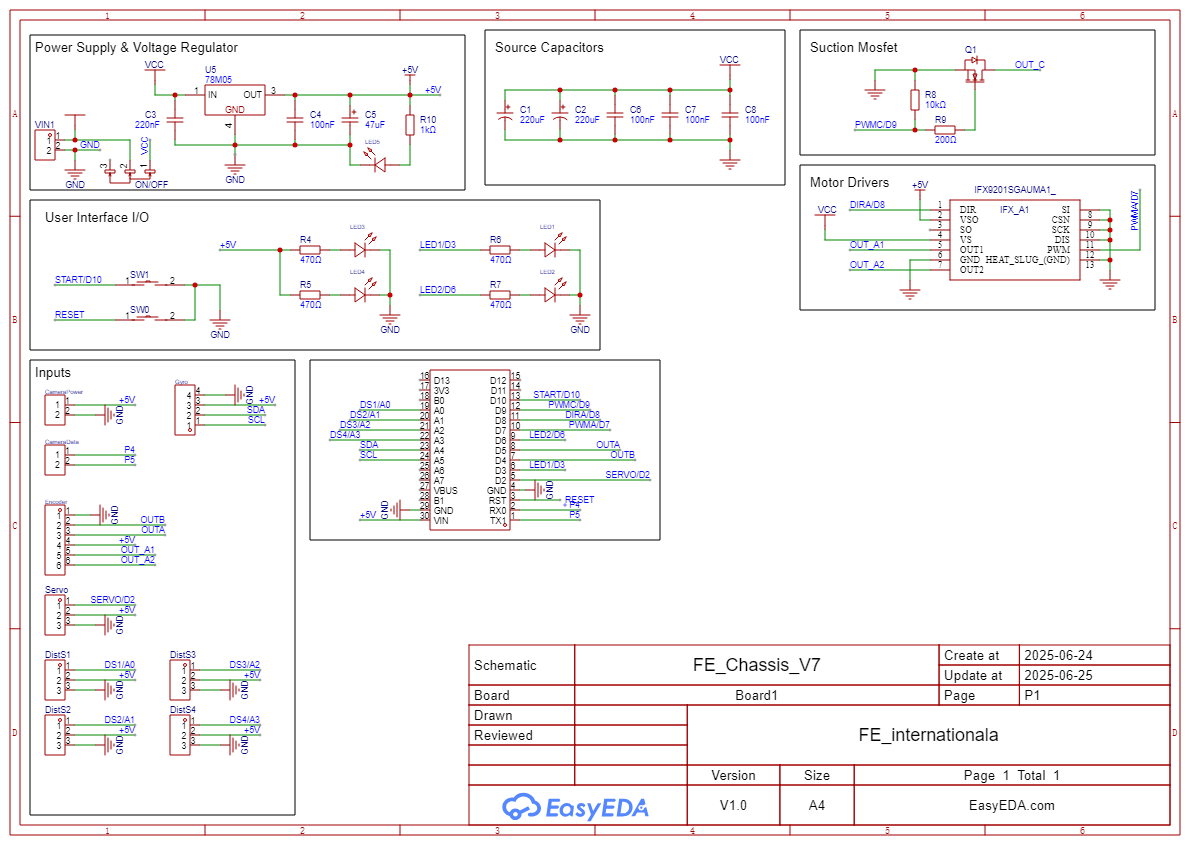
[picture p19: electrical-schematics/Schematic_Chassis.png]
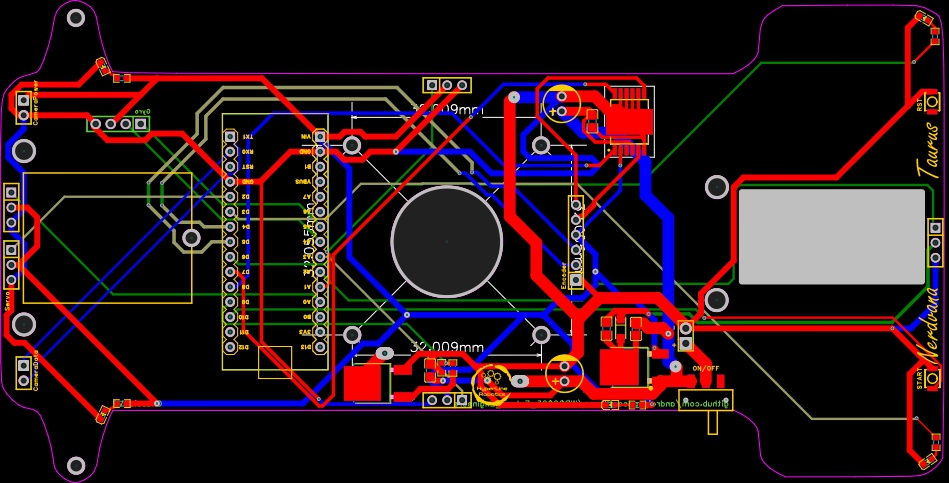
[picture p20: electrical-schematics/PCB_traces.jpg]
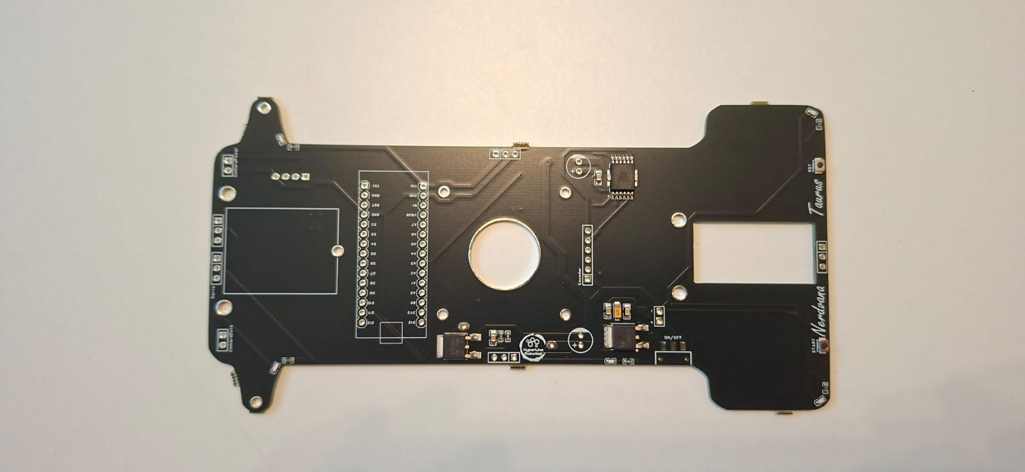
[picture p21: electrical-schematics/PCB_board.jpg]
|  |  |  |

**Advantages of a Custom PCB Chassis**  
✔ **Organized layout** ➜ Prevents loose connections & messy wiring  
✔ **Power stability** ➜ Ensures consistent voltage supply to all components  
✔ **Compact design** ➜ Reduces weight & optimizes space  
✔ **Reliability** ➜ Minimizes risk of failure due to poor wiring  
✔ **Resistance** ➜ Having a full PCB Chassis is more resistent compared to 3D printed parts glued or screwed together

---

### **⚡ Power Consumption Summary** 

| Item / Designators | Part | Supply | Typical Current | Peak Current | Notes |
| --- | --- | ---: | ---: | ---: | --- |
| Arduino Nano ESP32 | MCU board | 5 V | 200 mA | 500 mA | Wi-Fi/BLE spikes |
| Steering Servo (MG90S) | Servo | 5 V | 120 mA | 500 mA | Peak at start/stall |
| OpenMV H7 Camera | Camera | 5 V | 300 mA | 400 mA | If on 3.3 V, power is lower |
| BMI088 | IMU | 3.3 V | 3.2 mA | 4 mA | Negligible |
| **1020 Coreless Impeller (via ESC)** | Ducted fan | **7.4 V (VBAT)** | **0.6 A** | **1.8 A** | Load-dependent; startup spikes high |
| Pololu 6 V 30:1 HPCB Motor | DC motor | \~6 V | \~120 mA (no-load) | \~1.6 A (stall) | Running current depends on load |
| IFX9201SG (IFX\_A1) | Motor driver IC | 5 V (logic), VBAT (motor) | \~5 mA (logic) | \~10 mA (logic) | Motor current from VBAT |
| IRFR3411TRPBF-VB (Q1) | N-MOSFET | VBAT/5 V | ≈0 mA DC | — | Gate draw ≈0 DC |
| 78M05 (U5) | 5 V LDO | 7.4 V→5 V | 6 mA quiescent | 6 mA | Plus it sources all 5 V loads |
| LED5 | XL-1608SURC-06  | 5 V | 5 mA | 10 mA | Red, assumed 5 mA |
| LED1–LED4 | XL-1608UBC-04 | 5 V | 4×5 mA = 20 mA | \~40 mA | Blue, assumed 5 mA each |
| R8,R9,R10,R4–R7 | Resistors | — | \~0 mA | — | Included via LED rows |
| C3,C4,C5,C6,C8 | Capacitors | — | 0 | — | Reactive only |
| RST, START (B3U-1000P) | Tact switches | — | 0 | — | No DC draw |

---

## 💻 Components coding 

### ⚡ Drive motor 

The motor driver is based on the **Infineon IFX9201SG**, which allows us to directly manage the motor with only two control signals: a **PWM** pin that regulates speed, and a direction pin that selects forward or reverse rotation. Thanks to this chip’s integrated design, no external library was required for motor control.

We implemented a set of functions within our control system: one to initialize the driver, one to control motor velocity, and another to stop it effectively using an active braking routine. The function **move(int speed)** takes an input in the range **−255** to **+255**. The absolute value of the input is written to the **PWM channel**, while the sign determines the motor’s rotation direction. A dedicated **stop_motor()** function applies a short reverse torque pulse before setting the PWM duty cycle to zero, ensuring the robot stops quickly without uncontrolled coasting.

Since the robot is powered by an **ESP32**, **PWM** signals must be generated using the **LEDC** hardware utility, which provides stable and precise duty cycles.

```cpp
void motor_driver_setup() {
  pinMode(PWMA, OUTPUT);
  pinMode(DIRA, OUTPUT);
  ledcSetup(PWM_MOTOR_CHANNEL, PWM_MOTOR_FREQ, PWM_MOTOR_RESOLUTION);
  ledcAttachPin(PWMA, PWM_MOTOR_CHANNEL);
  move(0);
}

void move(int speed) {
  ledcWrite(PWM_MOTOR_CHANNEL, abs(speed));
  digitalWrite(DIRA, speed > 0 ? LOW : HIGH);
}

void stop_motor() {
  move(-3);
  delay(100);
  move(0);
}
```

For odometry, the motor includes an encoder. We implemented an interrupt-based approach to count ticks in real time, avoiding the need for a dedicated library. The encoder setup attaches an interrupt on the rising edge of channel A, and the distance traveled is computed from tick counts.

In this configuration, the encoder provides 12 counts per revolution, and by applying the gear ratio, wheel diameter, and π, we obtain a conversion factor of `MM_PER_TICK = 1.8326`. This enables the robot to measure traveled distance with centimeter-level accuracy, which is crucial for precise maneuvers during navigation.

```cpp
void encoder_setup() {
  // Enable pull-ups so A/B never float
  pinMode(ENCODER_A, INPUT_PULLUP);
  pinMode(ENCODER_B, INPUT_PULLUP);
  // Attach only A’s rising edge:
  attachInterrupt(digitalPinToInterrupt(ENCODER_A), encoderISR, RISING);
  encoder_ticks = 0;
}

float read_cm() {
  noInterrupts();
  int32_t t = encoder_ticks;
  interrupts();

  float dist_mm = t * MM_PER_TICK;
  float dist_cm = dist_mm / 10.0f;
  //Serial.printf("ticks=%ld  dist_cm=%.2f\n", t, dist_cm);
  return dist_cm;
}
```

### 🌪️ Impeller 

The impeller is responsible for generating downforce, which increases stability and traction when the robot operates at high speed. To control it, we use an **RFR3411 MOSFET**, wired as a low-side switch. This **MOSFET** can safely handle the high current required by the impeller, while allowing speed control via **PWM** modulation.

Only a single PWM pin from the ESP32 is needed to drive the MOSFET gate. The PWM duty cycle determines how much power is applied to the impeller:

```
0 = off
255 = full speed
```

Two functions were implemented for simplicity: one for initializing the PWM channel and one for setting the impeller speed.

```cpp
void impeller_setup() {
  pinMode(PWM_IMPELLER, OUTPUT);
  ledcSetup(PWM_IMPELLER_CHANNEL, PWM_IMPELLER_FREQ, PWM_IMPELLER_RESOLUTION);
  ledcAttachPin(PWM_IMPELLER, PWM_IMPELLER_CHANNEL);
}

void setImpeller(int _pwm) {
  ledcWrite(PWM_IMPELLER_CHANNEL, constrain(_pwm, 0, 255));
}
```

### 🎮 Servo motor 

The steering system is controlled by a **MG90S servo**, which adjusts the angle of the front wheels. This enables the robot to follow precise paths while maintaining stability during turns.

The servo is connected directly to the **ESP32** and driven using the `ESP32Servo.h` library interface. To ensure consistent and safe motion, we defined three reference positions:

```
STEERING_LEFT = 140
STEERING_CENTER = 85
STEERING_RIGHT = 40
```

These values were experimentally calibrated to match the geometry of the steering mechanism.

The function `steering_servo_setup()` attaches the servo to its pin, performs a left–right sweep to verify operation, and finally centers it. This ensures that the robot always starts in a straight-line configuration.

The function `steer(double steering_angle)` accepts an input in the range `[-1, 1]`, representing normalized steering:

```
-1 = maximum right
0 = centered
+1 = maximum left
```

The input is first clamped to stay within the allowed range, then mapped to the calibrated servo values using **map_double**. This abstraction allows higher-level controllers (such as PID) to provide normalized outputs without directly worrying about servo limits.

```cpp
void steering_servo_setup() {
  steeringServo.attach(STEERING_SERVO);
  delay(100);

  steeringServo.write(STEERING_LEFT);
  delay(300);
  steeringServo.write(STEERING_RIGHT);
  delay(300);
  steeringServo.write(STEERING_CENTER);
  delay(300);
}

void steer(double steering_angle) {
  // Clamp input between -1 and 1
  if (steering_angle > 1)  steering_angle = 1;
  if (steering_angle < -1) steering_angle = -1;

  // Map to servo range
  steering_angle = map_double(steering_angle, -1, 1, STEERING_LEFT, STEERING_RIGHT);
  steeringServo.write(steering_angle);
}
```

### 🧭 IMU 

To keep the robot on a straight path and execute precise turns, we rely on the **Bosch BMI088 Inertial Measurement Unit (IMU)**. This sensor combines a high-resolution accelerometer and gyroscope, and in our case we primarily use the **Z-axis** gyroscope for yaw angle estimation.

During initialization, the function `gyro_setup()` configures the BMI088 via **I²C** communication. The accelerometer is set to a **±6 g** range at **200 Hz**, while the gyroscope is set to **±2000 °/s** at **400 Hz** with a **47 Hz bandwidth**. These parameters provide a good balance between responsiveness and noise filtering.

A key challenge with gyroscopes is drift — the tendency of small measurement errors to accumulate over time. To correct this, the setup function performs a calibration routine: for a predefined duration **(DRIFT_TEST_TIME)**, the sensor’s output is averaged while the robot is stationary. The resulting bias **(drifts_z)** is subtracted from all subsequent readings.

```cpp
void gyro_setup() {
  // 1) Wire + basic init
  Wire.begin();
  imu.initialize();

  imu.setAccScaleRange(RANGE_6G);
  imu.setAccOutputDataRate(ODR_200);       // 200 Hz accel
  imu.setAccPoweMode(ACC_ACTIVE);

  imu.setGyroScaleRange(RANGE_2000);
  imu.setGyroOutputDataRate(ODR_400_BW_47); // 400 Hz, BW=47 Hz
  imu.setGyroPoweMode(GYRO_NORMAL);

  if (!imu.isConnection()) {
    if (debugGyro) {
      Serial.println("BMI088 connection failed!");
    }
    return;
  }

  if (debugGyro) Serial.println("Starting gyro drift calculation...");
  double start = millis();
  gyro_last_read_time = start;
  gz = 0;

  while (millis() - start < DRIFT_TEST_TIME * 1000) {
    double now = millis();
    double dt = (now - gyro_last_read_time) * 0.001; // s
    float rate = imu.getGyroscopeZ();                // °/s
    gz += rate * dt;                                 // accumulate degrees
    gyro_last_read_time = now;
  }

  drifts_z = gz / DRIFT_TEST_TIME;  // average °/s
  if (debugGyro) {
    Serial.print("Drift test done! drifts_z = ");
    Serial.print(drifts_z, 6);
    Serial.println(" °/s");
  }

  // reset integration
  gz = 0;
  gyro_last_read_time = millis();
} 
```

The function `read_gyro_data()` must be called continuously in the control loop. It computes the elapsed time **dt**, reads the current angular rate from the **BMI088**, subtracts the drift offset, and integrates the result into **gz**, which represents the robot’s absolute yaw angle in degrees. This value is used directly in the **PID controller** for heading correction.

```cpp
void read_gyro_data() {
  // call this frequently (e.g. every loop)
  double now = millis();
  double dt  = (now - gyro_last_read_time) * 0.001; // s          
  float rate = imu.getGyroscopeZ();              // °/s
  double corrected = rate - drifts_z;               // drift-compensated
  gz += corrected * dt;                             // integrate to degrees
  gyro_last_read_time = now;

  if (debugGyro) {
    Serial.print("Gyro angle (°): ");
    Serial.println(gz, 4);
  }
}
```

### 📡 Distance sensors 

The robot integrates four **Pololu PWM distance sensors**, placed on the **front, back, left, and right sides** of the chassis. Each sensor outputs a pulse width signal, where the duration is proportional to the measured distance. This gives us precise range data without requiring complex communication protocols.

The function `distanceSensorPin(DistanceDir d)` maps each logical direction (FRONT_DIR, LEFT_DIR, RIGHT_DIR, BACK_DIR) to its corresponding analog pin. Using `pulseIn()`, we measure the pulse width, and the helper function `pulseToMM()` converts it into millimeters based on the calibration constants:

```
PW_OFFSET_US – offset at ~0 mm (typically ~1000 µs)
PW_US_PER_MM – scaling factor (1 µs per mm)
PULSE_TIMEOUT_US – maximum waiting time for a valid pulse (30 ms)
```

If no valid pulse is received, the function returns **-1** to indicate a timeout.

```cpp
// ======= Pololu PWM Distance Sensor Settings =======
static const float PW_OFFSET_US   = 1000.0f; // microseconds offset at ~0 mm
static const float PW_US_PER_MM   = 1.0f;    // microseconds per millimeter
static const unsigned long PULSE_TIMEOUT_US = 30000UL; // 30 ms timeout

// ======= Map direction to the correct pin =======
static inline int distanceSensorPin(DistanceDir d) {
  switch (d) {
    case FRONT_DIR: return PWM_DIST_FRONT; // A0
    case LEFT_DIR:  return PWM_DIST_LEFT;  // A3
    case RIGHT_DIR: return PWM_DIST_RIGHT; // A1
    case BACK_DIR:  return PWM_DIST_BACK;  // A2
  }
  return PWM_DIST_FRONT;
}

// ======= Read pulse in microseconds =======
static inline unsigned long readPulseUS(int pin) {
  pinMode(pin, INPUT);
  return pulseIn(pin, HIGH, PULSE_TIMEOUT_US);
}

// ======= Convert pulse width to millimeters =======
static inline float pulseToMM(unsigned long pw_us) {
  if (pw_us == 0) return -1.0f; // timeout
  float mm = (float(pw_us) - PW_OFFSET_US) / PW_US_PER_MM;
  if (mm < 0) mm = 0;
  return mm;
}
```

### 📷 Camera 

Once the robot can move and steer, it also needs to see and react to the environment. For this, we use an **OpenMV camera module**, connected via **UART protocol**. This allows the camera to handle the heavy work of image processing and only send compact messages (like colors, cubes, or angles) to the **ESP32**.

The camera is wired to the **ESP32** as follows:
- Camera TX (P4) → ESP32 RX (D0)
- Camera RX (P5) → ESP32 TX (D1)

Both devices must share the same baud rate **(19200)**. On the **ESP32** side, we use `SoftwareSerial` for communication, while on the camera side, `UART(3, 19200)` is initialized.

**Arduino code:**

```cpp
// UART to OpenMV (SoftwareSerial on D0/D1)
#include <SoftwareSerial.h>
SoftwareSerial cameraSerial(D0, D1); // RX=D0, TX=D1

String receivedMessage;

void comm_setup() {
  Serial.begin(9600);
  cameraSerial.begin(19200);          // must match OpenMV baudrate
  receivedMessage = "";
  // (optional) small flush
  while (cameraSerial.available()) cameraSerial.read();
}

void loop() {
  // ... control loop stuff ...

  // Execute pending commands from camera
  while (cameraSerial.available() > 0) {
    char c = cameraSerial.read();
    if (c == '\n') {
      // Optionally skip commands while parking
      if (CASE != PARK) {
        execute_command(receivedMessage); // handle "S<angle>", "BLUE", "ORANGE", "RED", "GREEN", "BLACK", "1", "2"
      }
      receivedMessage = "";
    } else {
      receivedMessage += c;
    }
  }
}
```

**Camera code:**

We use `UART(3, 19200)` on **OpenMV (P4=TX, P5=RX)**. Baud must match the Arduino side.

```python
from pyb import UART
uart = UART(3, 19200)
# 3 → uses P4 (TX) and P5 (RX)
# 19200 → baud rate, must match Arduino
```

Arduino listens and executes messages line-by-line (ending with `\n`). Camera only sends.

We configure the camera for `RGB565, QVGA (320×240)`, flipped to match mounting, and fixed exposure/gain/WB for consistent LAB thresholds.

```python
import sensor, time
sensor.reset()
sensor.set_pixformat(sensor.RGB565)
sensor.set_framesize(sensor.QVGA)     # 320x240
sensor.set_vflip(True)
sensor.set_hmirror(True)

sensor.set_auto_gain(False)           # must be off for color tracking
sensor.set_auto_whitebal(False)       # must be off for color tracking
sensor.set_auto_exposure(False, exposure_us=10000)  # ~10ms
sensor.skip_frames(time=2000)

clock = time.clock()
```

Why fixed exposure? It keeps color thresholds stable across frames and lighting.

Color thresholds **(LAB)** for red/green cubes, blue/orange lines, black walls.
We also define ROIs to look only where each object should appear (faster + fewer false positives).

```python
# ---- LAB thresholds ----
red_threshold    = [(32, 54, 40, 67, 17, 63)]
green_threshold  = [(36, 69, -56, -21, -19, 32)]
blue_threshold   = [(9, 76, -45, 27, -57, -8)]
orange_threshold = [(62, 91, -3, 43, 5, 69)]
pink_threshold   = [(30, 70, 10, 60, -15, 15)]
black_threshold  = [(0, 37, -26, 7, -17, 11)]

# ---- Regions of Interest ----
img_h, img_w = sensor.height(), sensor.width()
cubes_roi      = (0, int(img_h * 0.4),  img_w,        int(img_h * 0.6))  # bottom area
lines_roi      = (5, int(img_h * 0.5),  img_w - 10,   int(img_h * 0.4))  # lower band
wall_roi       = (50, int(img_h * 0.5 - 18), img_w - 100, int(img_h * 0.2 - 10))
final_wall_roi = (30, 80, img_w - 60, int(img_h - 60))
```

Minimum areas to reject noise and a simple **PD** setup for cube following.

```python
min_cube_size       = 300
min_line_size       = 800
min_area            = 10
min_valid_cube_area = 450
black_wall_min_area = 7000
final_black_wall_min_area = 9000
min_black_height    = 39

kp_cube = 0.21
kd_cube = 2.4
pid_error = 0.0
pid_last_error = 0.0
follow_threshold = 4100

direction = 0  # 0 = unset, 1 = LEFT(blue), 2 = RIGHT(orange)

def get_largest_blob(blobs):
    return max(blobs, key=lambda b: b.area(), default=None)
```

Every frame, we:
- Detect walls (parking / turn signal) → send `"BLACK"`
- Detect cubes (red/green) → send `S<error>` for follow, or `RED/GREEN` when very close
- Detect lines (blue/orange) → send `"BLUE"/"ORANGE"` and set direction (1/2)
- Always send the current direction **("1"/"2")** for sync

```python
while True:
    clock.tick()
    img = sensor.snapshot()
    target_x = img_w // 2

    # ---- Walls / parking ----
    black_blobs = img.find_blobs(black_threshold, roi=final_wall_roi,
                                 pixels_threshold=final_black_wall_min_area,
                                 area_threshold=final_black_wall_min_area, merge=True)
    black_blob = get_largest_blob(black_blobs)
    if black_blob and black_blob.h() >= min_black_height:
        uart.write("BLACK\n")

    # ---- Cubes (red/green) ----
    red_blobs   = img.find_blobs(red_threshold,   roi=cubes_roi,
                                 pixels_threshold=min_cube_size,
                                 area_threshold=min_cube_size, merge=True)
    green_blobs = img.find_blobs(green_threshold, roi=cubes_roi,
                                 pixels_threshold=min_cube_size,
                                 area_threshold=min_cube_size, merge=True)

    red_cube   = get_largest_blob([b for b in red_blobs   if b.area() >= min_valid_cube_area])
    green_cube = get_largest_blob([b for b in green_blobs if b.area() >= min_valid_cube_area])

    candidates = []
    if red_cube:   candidates.append(('RED',   red_cube))
    if green_cube: candidates.append(('GREEN', green_cube))

    if candidates:
        color, cube = max(candidates, key=lambda x: x[1].area())
        # normalized horizontal error in [-1..1]
        error = (cube.cx() - target_x) / float(target_x)
        pid_error = kp_cube * error + kd_cube * (error - pid_last_error)
        pid_last_error = error

        if cube.area() < follow_threshold:
            uart.write("S{:+.3f}\n".format(error))   # steer hint for FOLLOW_CUBE
        else:
            uart.write(color + "\n")                 # close: just report color

    # ---- Lines (blue/orange) ----
    blue_blobs   = img.find_blobs(blue_threshold,   roi=lines_roi,
                                  pixels_threshold=min_line_size,
                                  area_threshold=min_line_size, merge=True)
    orange_blobs = img.find_blobs(orange_threshold, roi=lines_roi,
                                  pixels_threshold=min_line_size,
                                  area_threshold=min_line_size, merge=True)

    blue_line   = get_largest_blob([b for b in blue_blobs])
    orange_line = get_largest_blob([b for b in orange_blobs])

    chosen = None
    if blue_line and orange_line:
        chosen = "BLUE" if blue_line.area() > orange_line.area() else "ORANGE"
    elif blue_line:
        chosen = "BLUE"
    elif orange_line:
        chosen = "ORANGE"

    if chosen:
        uart.write(chosen + "\n")
        if direction == 0:
            direction = 1 if chosen == "BLUE" else 2

    # ---- Always send current turn direction ----
    uart.write(str(direction) + "\n")
```

---

## 📝 Obstacle Management 

### 🏁 Open Round 
During the **Open Round**, our robot follows a **straight trajectory using a PID controller based on gyro yaw**, ensuring stable movement. To determine turns, the **camera detects Orange and Blue lines** on the track:
- **Orange Line ➜ Right Turn**
- **Blue Line ➜ Left Turn**
- The turn is executed when the robot reaches an approximate **distance from the front black wall**.

#### **Camera Processing for Line Detection**
The camera captures frames in **RGB565** format and processes color blobs using **LAB thresholds** to detect relevant track elements. Below is a **snippet of the camera’s core logic** that identifies **track lines and determines turning direction**:

```python
# Detect Blobs
red_blobs = img.find_blobs(red_threshold, roi=cubes_roi, pixels_threshold=min_cube_size, area_threshold=min_cube_size, merge=True)
green_blobs = img.find_blobs(green_threshold, roi=cubes_roi, pixels_threshold=min_cube_size, area_threshold=min_cube_size, merge=True)
blue_blobs = img.find_blobs(blue_threshold, roi=lines_roi, pixels_threshold=min_line_size, area_threshold=min_line_size, merge=True)
orange_blobs = img.find_blobs(orange_threshold, roi=lines_roi, pixels_threshold=min_line_size, area_threshold=min_line_size, merge=True)
black_blobs = img.find_blobs(black_threshold, roi=cubes_roi, pixels_threshold=min_cube_size, area_threshold=min_cube_size, merge=True)

...

# Determine Direction
if direction == 0:
    if orange_line and not is_invalid_orange(orange_line, red_blobs):
        direction = 2  # Orange line first ➜ turn right
    elif blue_line:
        direction = 1  # Blue line first ➜ turn left

# Send Direction Command
uart.write(str(direction) + '\n')
```

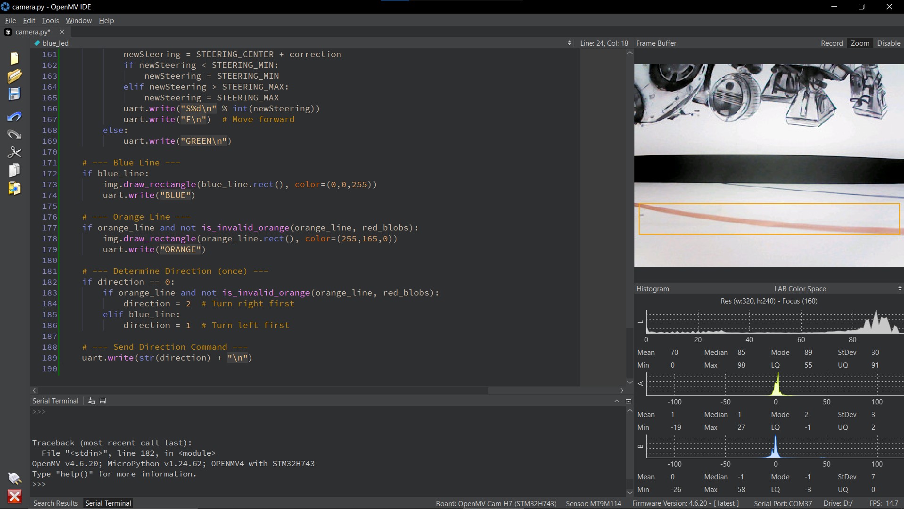
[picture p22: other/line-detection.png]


### ⚡ Final Round 

In the final round, we extend our open rount algorithm by adding real‐time cube detection, following, and avoidance algorithms. The OpenMV H7 camera handles live frames processing and sends compact UART messages to the Arduino Nano ESP32. On the Arduino, incoming UART messages drive a four‐state algorithm: in **PID**, the robot adjust to hold a straight heading by using a PD on the gyro and turns 90° whenever it receives a **BLACK** signal (lap turning point in each corner). In **FOLLOW_CUBE**, the camera’s **S<corrected_servo>** message directly sets the servo angle to chase the closest visible cube; if no follow message arrives within 250-500 ms, it returns to **PID** as the cube might have been passed or lost from the view. When a proximity trigger (**RED** or **GREEN**, **R** or **G**) arrives, it switches to **AVOID_CUBE**, executes a 37° turn plus an 8 cm clear‐away while holding that heading, then enters **AFTER_CUBE** to reallign on gyro while moving back to center section of each side of the map, and to flush the leftover commands before reverting to **PID**.

---

### Arduino Side

#### States Driving Logic

This `switch` statement runs inside `void loop()` and decides what the robot does in each of the four states.

```cpp
switch (currentState) {

  case PID:
    {
      // PID straight‐drive, maintain heading using gyro PD
      double err = current_angle_gyro - gz;
      pid_error        = (err) * kp + (pid_error - pid_last_error) * kd;
      pid_last_error   = pid_error;
      steer(pid_error);
      move(robot_speed);
      break;
    }

  case FOLLOW_CUBE:
    {
      // If no follow command arrives within 250-500ms, go back to gyro PD
      if (millis() - last_follow_cube > FOLLOW_CUBE_LOST_TIME) {
        currentState = PID;
      }
      // Otherwise, steer directly toward the cube, so we do active cube following, using a PD that runs on the camera
      steer(follow_cube_angle);
      move(robot_speed);
      break;
    }

  case AVOID_CUBE:
    {
      // Perform the hard coded avoidance maneuver
      pass_cube(cube_avoid_direction);
      break;
    }

  case AFTER_CUBE:
    {
      // Return to PID after getting to be straight again, while ignoring all commands
      while (millis() - last_cube_time > 1500) {
        read_gyro_data();
        double error = current_angle_gyro - gz;
        pid_error = (error)*kp + (pid_error - pid_last_error) * kd;
        pid_last_error = pid_error;
        if (debug == true) {
          Serial.print(current_angle_gyro);
          Serial.print("     |      ");
          Serial.print(turn_direction);
          Serial.print("     |      ");
          Serial.print(gz);
          Serial.print("     |      ");
          Serial.println(robot_speed);
        }
        steer(pid_error);
        move(robot_speed);
      }
      currentState = PID;
      cameraSerial.flush();
      break;
    }
}
```

**PID:**
- Uses a PD loop on the integrated gyro yaw (`gz`) vs. desired heading (`current_angle_gyro`).
- Calls `steer(pid_error)` and `move(robot_speed)` to drive straight.

**FOLLOW_CUBE:**
- If we haven’t received a new `"S…\n"` follow message for at least 250-500 ms, assume the cube is lost or passed and switch back to **PID**.
- Otherwise, use `follow_cube_angle` (sent by the camera) to set the servo and follow the cube.

**AVOID_CUBE:**
- Calls `pass_cube(cube_avoid_direction)`, which executes a turn to left or right based on the cube color. This code sequence is hard coded.
  
**AFTER_CUBE:**
- Return to **PID** after getting to be straight again, while ignoring all commands.

 #### UART Command Parser (execute_command())
 
This function is called whenever a complete line arrives over **UART**. It selects which state to enter (**PID**, **FOLLOW_CUBE**, **AVOID_CUBE**) or adjusts gyro target angle on a **BLACK** message by adding or removing 90 degrees, based on the turn direction.

```cpp
void execute_command(String cmd) {
  cmd.trim();
  cmd.toUpperCase();

  // “S…” steering to follow cube ➜ FOLLOW_CUBE
  if (cmd.startsWith("S") && RUN_MODE == 1) {
    float val = cmd.substring(1).toFloat();
    follow_cube_angle = val;
    currentState      = FOLLOW_CUBE;
    last_follow_cube  = millis();

    if (debug) {
      Serial.print("FOLLOW_CUBE angle ➜ ");
      Serial.println(follow_cube_angle);
    }
    return;
  }

  // Map color words to one letter commands and set turn_direction on first BLUE/ORANGE
  char c = cmd.charAt(0);
  if      (cmd.indexOf("BLACK")  != -1) { c = 'B'; }
  else if (cmd.indexOf("BLUE")   != -1) { c = 'L'; lastLineDetectedTime = millis(); if (turn_direction == 0) turn_direction = -1; }
  else if (cmd.indexOf("ORANGE") != -1) { c = 'O'; lastLineDetectedTime = millis(); if (turn_direction == 0) turn_direction =  1; }
  else if (cmd.indexOf("RED")    != -1) { c = 'R'; }
  else if (cmd.indexOf("GREEN")  != -1) { c = 'G'; }
  else if (cmd.indexOf("PINK")   != -1) { c = 'P'; }
  else { return; }  // Ignore any other strings

  // “BLACK” turn 90° if in PID
  if (currentState == PID) {
    if (c == 'B' || (millis() - lastLineDetectedTime > 1800 && lastLineDetectedTime > 0)) {
      if (millis() - lastTurnTime < 1000) {
        if (debug) Serial.println("Ignoring repeated 'B' command due to cooldown.");
        return;
      }
      if (debug) Serial.println("Received 'BLACK' command. Turning 90°...");
      current_angle_gyro += turn_direction * 90;
      turn_count++;
      lastTurnTime         = millis();
      lastLineDetectedTime = 0;
      return;
    }
  }

  // “RED” or “GREEN” close to a cube and need to avoid it ➜ AVOID_CUBE
  if ((c == 'R' || c == 'G') && millis() - last_cube_time >= AVOIDANCE_DRIVE_TIME) {
    cube_avoid_direction = (c == 'R') ? 'L' : 'R';  // 'R' means turn left, 'G' turn right
    currentState         = AVOID_CUBE;
    last_cube_time       = millis();
    if (debug) {
      Serial.print("AVOID_CUBE dir ➜ ");
      Serial.println(cube_avoid_direction);
    }
    return;
  }

  if (debugcam) {
    Serial.print("Ignored cmd ➜ ");
    Serial.println(cmd);
  }
}
```

**“S…” (e.g. `"S+0.120\n"`):**
- Parses the float after `S`, sets `follow_cube_angle` to the value that was sent after S character, and switches to **FOLLOW_CUBE**.
- Records the time to `last_follow_cube` so we know how long it has been since the camera last issued a “follow” command.

**“BLACK”:**
- Only when in **PID**, add or substract 90° based on the lap direction, by adjusting `current_angle_gyro += ±90`.
- Increment `turn_count` and enforce a 1 s cooldown to avoid repeated turning signals.

**“RED” or “GREEN”:**
- When getting to close to a cube, it sets `cube_avoid_direction` based on the cube color and enter **AVOID_CUBE**.

#### Cube Avoidance Subroutine (pass_cube())
When in **AVOID_CUBE**, the robot executes a hardcoded movement, that includes a fixed turn + move forward maneuver to avoid the cube, then transitions to **AFTER_CUBE**, that alligns the robot for doing **PID** and follow the next cube.

```cpp
void pass_cube(char cube_direction) {
  read_gyro_data();
  // Convert 'R' ➜ +1 (turn left), 'G' ➜ -1 (turn right)
  int sign = (cube_direction == 'R') ? 1 : -1;

  double start_angle  = gz;
  double target_angle = start_angle - sign * AVOIDANCE_ANGLE;

  // Turn ~37° away from cube
  move_until_angle(robot_speed, target_angle);

  // Drive ~8 cm forward while holding that heading
  move_cm_gyro(8, robot_speed, target_angle);

  // Move to AFTER_CUBE case
  last_cube_time = millis();
  currentState   = AFTER_CUBE;

  // Discard any leftover UART messages before returning to PID
  flush_messages();
}
```

### Camera Side (OpenMV H7)
In the OpenMV python script, we detect the largest visible red or green blob in the bottom 40% section of the frame, while computing a PD steering error, and send either a small follow command "S±pid_error\n" or an avoid trigger "RED\n"/"GREEN\n" over UART.

**Choose Closest Cube & Follows it by using a PD algorithm**

```python
# ---- Choose Closest Cube (largest red or green) ----
candidates = []
if red_cube:   candidates.append(('R', red_cube))
if green_cube: candidates.append(('G', green_cube))

if candidates:
    # Pick the cube (red or green) with the largest area
    color_char, cube = max(candidates, key=lambda x: x[1].area())
    area = cube.area()
    col  = (255,0,0) if color_char == 'R' else (0,255,0)

    # Draw rectangle and crosshair on the selected cube
    img.draw_rectangle(cube.rect(), color=col)
    img.draw_cross(cube.cx(), cube.cy(), color=col)
    img.draw_string(cube.x(), cube.y() + cube.h() - 10,
                    str(area), color=col)

    # Compute normalized horizontal error in [-1, 1]
    error = (cube.cx() - target_x) / float(target_x)
    pid_error = kp_cube * error + kd_cube * (error - pid_last_error)
    pid_last_error = error

    if area < follow_threshold:
        # Send “S±error\n” to indicate a small servo correction (➜ FOLLOW_CUBE)
        uart.write("S{:+.3f}\n".format(error))
        if DEBUG:
            print("{} FOLLOW ➜ err:{:+.3f}, pid:{:+.3f}, area:{}".format(
                  "RED" if color_char == 'R' else "GREEN",
                  error, pid_error, area))
    else:
        # At close range, send just “RED\n” or “GREEN\n” to trigger avoidance
        uart.write(("RED\n" if color_char == 'R' else "GREEN\n"))
        if DEBUG:
            print("{} CLOSE ➜ area {} >= {}".format(
                  "RED" if color_char == 'R' else "GREEN",
                  area, follow_threshold))
```

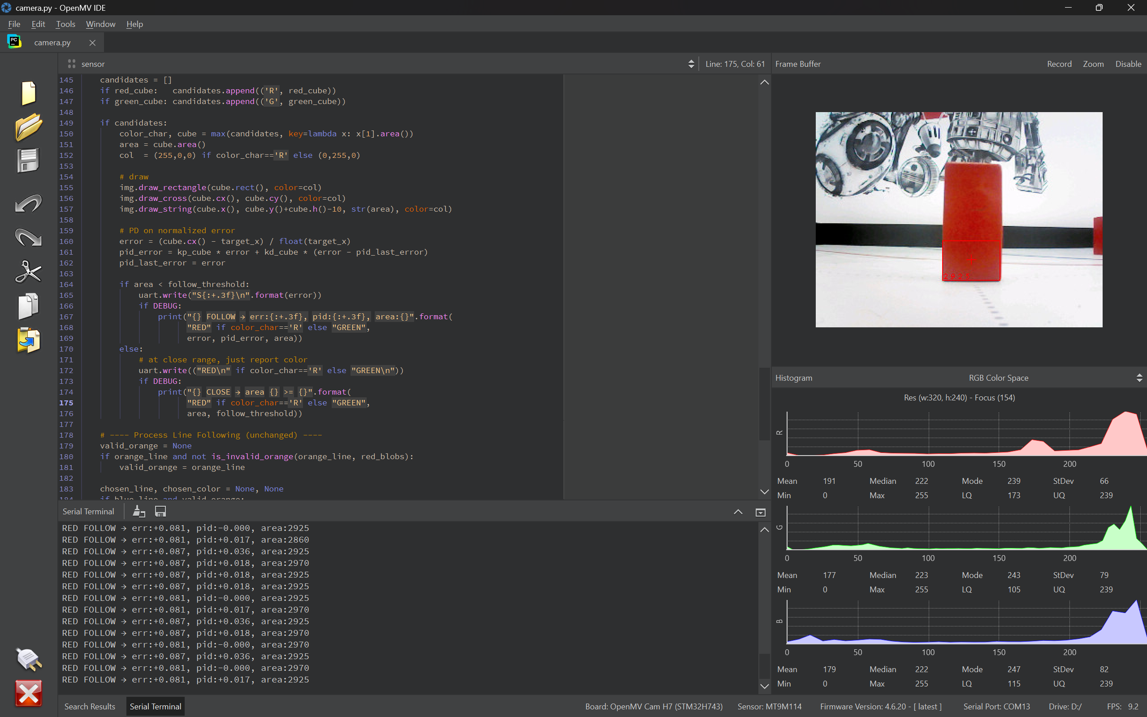
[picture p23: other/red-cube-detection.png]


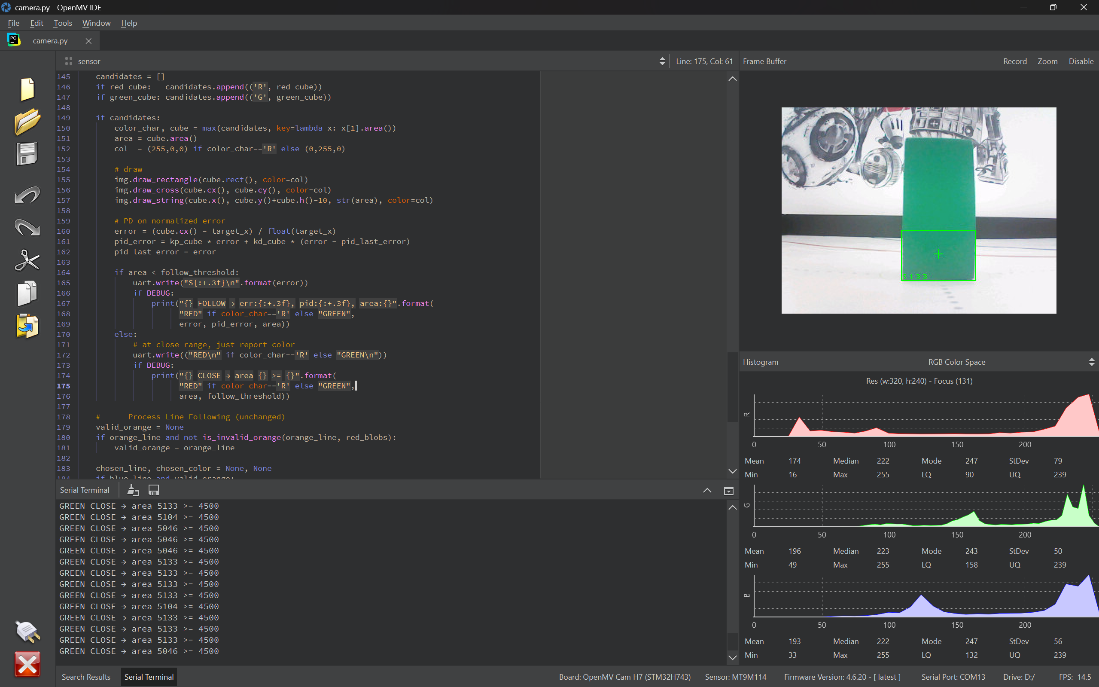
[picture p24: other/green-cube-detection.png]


### 🅿️ Starting from Parking 
At the start of the round, our robot is placed in the designated parking zone (the parking zone is 1.5x robot lenght). To determine the direction of the first lap (clockwise or counterclockwise), we use the 2 distance sensors placed on left and right side of our robot, the one that sees the wall further away will be the side to exit and do the laps.

Once the direction is determined, the robot performs an initial steering exit maneuver (to left or right) using our custom PD-based turning function:

```cpp
// Start from parking
if (RUN_MODE == 1) {
  if (readDistanceMM(LEFT_DIR, 3) < readDistanceMM(RIGHT_DIR, 3)) {  // exit right
    move_until_angle_max(exit_speed, 75);

    move(65);
    delay(100);

    turn_direction = 1;
    move_until_angle_max(exit_speed, 0);

    move_straight_on_gyro(-robot_speed, 900); // allign the robot to be able to pass cubes
  } else {  // exit left
    move_until_angle_max(exit_speed, -70);

    move(65);
    delay(100);

    turn_direction = -1;
    move_until_angle_max(exit_speed, 0);

    move_straight_on_gyro(-robot_speed, 1800); // allign the robot to be able to pass cubes
  }
}
```

The robot turns ~75° toward the main track depending on the detected direction. Following this parking exit, the robot enters its standard operating state:
- If it detects a cube, it enters **FOLLOW_CUBE** mode, where it tries to center itself on the cube using a PD algorithm.
- If the cube gets **too** close, it enters **AVOID_CUBE** mode, passing the cube left or right based on its color.
- After **AVOID_CUBE**, it automatically enters **AFTER_CUBE**, where it centers itself on the center of the track to prepare for searching the next cube.
- When no cube is detected, it enters **PID** mode, in which it simply navigates straight using the gyro—just as in qualification runs.

### 🅿️ Parking 

At the end of the run, once the robot has completed **12 turns in RUN\_MODE 1** (final run mode), it transitions into the **parallel parking sequence**. This routine is fully deterministic and relies on both **front and back distance sensors** together with the **gyro angle** to achieve a repeatable and precise result. The sequence consists of four main phases:

**1. Front-Wall Alignment**

The robot first drives forward until it reaches a **target offset from the front wall**, ensuring a consistent starting position for the parking maneuver.

* **Left course:** 470 mm from the front wall
* **Right course:** 460 mm from the front wall

This distance lock guarantees that the robot always starts the parking procedure at the same longitudinal reference point.

**2. Lane Reorientation**

Next, the robot performs a **90° snap turn** into the parking lane:

* **Heading update:** `current_angle_gyro += turn_direction * 90`
* **Correction:** On left courses, an additional `-3°` trim is applied for drift compensation.

This ensures the chassis is now parallel to the parking lane wall.

**3. Lane Squaring & Staging**

The robot then stabilizes its position inside the lane using a two-step process:

* Moves forward **200 mm** while holding the new heading (gyro-straight).
* Aligns on the **rear wall** by driving backwards until the back sensor reads **300 mm**.

Finally, it advances to a **staging distance** inside the lane, preparing for the parking maneuver:

* **Left course:** 900 mm from the front wall
* **Right course:** 1590 mm from the front wall

This places the robot in the correct position to start the 3-move parallel park.

**4. Three-Maneuver Parallel Parking**

The actual parallel parking is executed as three steering sweeps:

* **Left Course (`turn_direction = -1`)**

  1. **Reverse Arc:** Turn at `-75°` relative to prking spot.
  2. **Straighten Backwards:** Reduce angle to `-5°`.
  3. **Forward Tuck:** Correct forward sweep to `+5°`.

* **Right Course (`turn_direction = +1`)**

  1. **Reverse Arc:** Turn at `+75°` relative to parking spot.
  2. **Straighten Backwards:** Reduce angle to `+5°`.
  3. **Forward Tuck:** Correct forward sweep to `-2°`.

This sequence positions the robot in the parking zone, parallel to the wall and within the designated area.

**5. Final Stop**

Once the three-step maneuver is complete, the robot:

* Centers the steering servo.
* Cuts motor power (`move(0)`).
* Enters a **20-second idle state**, ending the run.

Code (for both lap directions):

```cpp
...
if (turn_count == 12 && RUN_MODE == 1) {
  move_straight_on_gyro(robot_speed, 500);
  if (turn_direction == -1) {
    move_to_distance(FRONT_DIR, 470.0f, 10.0f, 55, current_angle_gyro);
    current_angle_gyro += turn_direction * 90;
    current_angle_gyro -= 3;

    move_until_angle_max(60, current_angle_gyro);
    move_straight_on_gyro(robot_speed, 200);
    move_to_distance(BACK_DIR, 300.0f, 10.0f, -55, current_angle_gyro);
    move_to_distance(FRONT_DIR, 900.0f, 10.0f, 55, current_angle_gyro);

    // sensu de stanga
    move_until_angle_max(-60, (current_angle_gyro) - 75);
    move_until_angle_max(-60, (current_angle_gyro) - 5);
    move_until_angle_max(60, (current_angle_gyro) + 5);
  } else {
    move_to_distance(FRONT_DIR, 460.0f, 10.0f, 55, current_angle_gyro);
    current_angle_gyro += turn_direction * 90;

    move_until_angle_max(60, current_angle_gyro);
    move_straight_on_gyro(robot_speed, 200);
    move_to_distance(BACK_DIR, 300.0f, 10.0f, -55, current_angle_gyro);
    move_to_distance(FRONT_DIR, 1590.0f, 10.0f, 55, current_angle_gyro);

    move_until_angle_max(-63, (current_angle_gyro)+75);
    move_until_angle_max(-63, (current_angle_gyro)+5);
    move_until_angle_max(60, (current_angle_gyro)-2);
  }

  steeringServo.write(STEERING_CENTER);
  delay(300);

  move(0);
  delay(20000);
}
...
```

---

## 📽️ Performance Video 

🔗 **[Click here to watch the video on YouTube(without music)](https://youtu.be/p8Ov2znsIGI)** 
🔗 **[Click here to watch the video on YouTube(with music)](https://youtu.be/SGFatJyjOqs)** 

---

## 💰 Cost Analysis 
We have optimized our robot for **performance vs. cost efficiency**. The total cost includes motors, sensors, electronics, PCB, 3D printing and custom parts.

### 📦 **Components Costs** 

| Component | Quantity | Unit Price ($) | Total ($)  |
|---|---|---|---|
| **Arduino Nano ESP32** | 1 | **21.42** | **21.42** |
| **Drive Motor 6V (30:1 HPCB)** | 1 | **22.45** | **22.45** |
| **IFX9201SG Motor Driver** | 1 | **19.92** | **19.92** |
| **Steering Servo (MG90S)** | 1 | **4.05** | **4.05** |
| **OpenMV H7 Camera** | 1 | **80.00** | **80.00** |
| **Gyroscope (BMI088)** | 1 | **8.50** | **8.50** |
| **Pololu Distance Sensor** | 4 | **17.95** | **71.80** |
| **LiPo Battery (2S 300mAh)** | 1 | **5.60** | **5.60** |
| **D24V50F5 Voltage Regulator** | 1 | **29.95** | **29.95** |
| **Custom Silicone Wheels** | 4 | **9.24** | **36.96** |
| **RC Differential** | 1 | **4.00** | **19.04** |
| **Experimental Parts** | | **35.00** | **35.00** |
| **TOTAL COMPONENT COST** | - | **-** | **354.39**  |

**Experimental Parts**

- **MPU6050**  
  A compact IMU that's easy to integrate. However, it comes with several disadvantages, such as significant drifting over short time, even when using a Kalman filter for correction.

- **Pololu 30:1 Micro Metal Gearmotor**  
  A powerful and compact motor. The main issue is that it was the no encoder version and couldn't add the encoder, making it difficult to achieve precise control.

---

### **🔌 PCB Cost (Manufactured via JLCPCB)** 
| PCB Component | Quantity | Unit Price ($) | Total ($)  |
|---|---|---|---|
| **PCB Manufacturing (JLCPCB)** | 5 | **7.82** | **39.10** |
| **PCB Assembly (JLCPCB)** | 5 | **14.55** | **72.75** |
| **TOTAL PCB COST** | - | **-** | **111.85** |

---

### **🖨️ 3D Printing Cost Breakdown** 
| 3D Printed Parts | Quantity | Unit Price ($) | Total ($) |
|---|---|---|---|
| **1000g filament (PLA and PLA-CF)** | 1 | **20.00** | **20.00** |
| **TOTAL 3D PRINTING COST** | - | **-** | **20.00** |

---

### **🔩 Other Materials (Screws, Nuts, and Miscellaneous)** 
| Material | Quantity | Unit Price ($) | Total ($) |
|---|---|---|---|
| **M3 Screws & Nuts Set** | - | **-** | **4.00** |
| **Wiring & Connectors** | - | **-** | **5.00** |
| **TOTAL OTHER MATERIALS COST** | - | **-** | **9.00** |

---

### **💵 TOTAL** 
| Category | Total Cost ($) |
|---|---|
| **Components** | **325.24** |
| **PCB (JLCPCB + Components)** | **111.85** |
| **3D Printing** | **20.00** |
| **Other Materials** | **9.00** |
| **TOTAL PROJECT COST** | **466.09** |

**Prices are approximate, based on current market prices.*

---

## 📂 Resources 

Below is a list of **external images** used in this repository.
- **[Arduino Nano ESP32](https://store.arduino.cc/cdn/shop/files/ABX00092_01.iso_804x603.jpg?v=1727101612)**
- **[BMI088 IMU Sensor](https://files.seeedstudio.com/wiki/Grove-6-Axis_Accelerometer-Gyroscope-BMI088/img/main.jpg)**
- **[OpenMV H7 Camera](https://openmv.io/cdn/shop/products/new-cam-v4-angle-hero-web_1000x.jpg?v=1715735352)**
- **[Pololu 30:1 Gearmotor](https://a.pololu-files.com/picture/0J12418.220.jpg?8f026fe1675b1109ea574290d3d26081)**
- **[MG90S Steering Servo](https://static.optimusdigital.ro/20565-large_default/mg90s-servomotor.jpg)**
- **[D24V50F5 Voltage Regulator](https://gomagcdn.ro/domains/robofun.ro/files/product/original/pololu-5v-5a-step-down-voltage-regulator-d24v50f5-633511-832-442353.jpg)**
- **[2S 300mAh Li-Po Battery](https://img-va.myshopline.com/image/store/2000408386/1640672930478/GNB3002S60AHV-(4)_1800x.jpeg?w=1000&h=1000)**
- **[IFX9201SG Motor Driver](https://assets.lcsc.com/images/lcsc/900x900/20230316_Infineon-Technologies-IFX9201SG_C112633_front.jpg)**
- **[Pololu Distance Sensor](https://a.pololu-files.com/picture/0J11135.1200.jpg?1910ced553e34153046a4c95021a93b3)**
  
---

## 📜 License 
```
License – All Rights Reserved

Copyright (c) 2025 **Popescu Filimon Andrei Cosmin**
All rights reserved.

This software and all associated files are the exclusive property of the copyright holder.

* You **may not copy, modify, merge, publish, distribute, sublicense, or sell** any part of this software without prior written permission.
* The software may only be viewed from this repository for personal and educational reference purposes.
* Any unauthorized use, reproduction, or distribution is prohibited and subject to legal action.

THE SOFTWARE IS PROVIDED "AS IS", WITHOUT WARRANTY OF ANY KIND.
```

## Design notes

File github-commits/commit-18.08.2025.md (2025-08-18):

Commit - 08/08/2025

* Updated all the necessary information
* Added assembly instruction and video
* Added code description for each component
* Finished writing mobility management and other categories.
* Updated all technical drawings
* Left to update: parking, and performance video

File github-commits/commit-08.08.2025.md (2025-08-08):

Commit - 08/08/2025

- Removed old files and data from the previous robot used in national stage.
- Uploaded new hardware data of the new robot.
- Uploaded robot images.
- Uploaded new 3D models of the parts user in the new robot.
- Updated electric schematics and PCB with the ones used for the new robot.
- Updated src with the code used on the new robot.
- Updated README with the new robot specification. Still work to do.

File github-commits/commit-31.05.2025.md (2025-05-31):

Commit - 31/05/2025

- Uploaded current robot codes.
- Created and uploaded our performance video. (https://youtu.be/ZELCxp2fEmI?si=_0gKM8rAUfyjFkyQ)
- Uploaded all needed documentation. (Final, Start from Parking, and Parking)

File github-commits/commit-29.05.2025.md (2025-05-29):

Commit - 29/05/2025

- Updated all 3D models to the current ones
- Updated technical drawings
- Created and uploaded steering animation
- Updated prices and added experimental parts used and costs of them + reasons why not being used
- Updated robot photos
- Created our robot assembly timelapse: https://www.youtube.com/watch?v=sz8ePobdi_c
- Updated the assembly instructions

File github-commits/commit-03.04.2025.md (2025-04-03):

Commit - 03/04/2025

- Fixed robot images orientation
- Updated gyro code so now it uses 1D Kalman Filter

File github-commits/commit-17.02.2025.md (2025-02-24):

Commit - 17/02/2025

- Decided to give up on ultrasonic sensors and moved to all decision based on camera.
- Uploaded first version of camera.py code.

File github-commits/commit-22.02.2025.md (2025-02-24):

Commit - 22/02/2025

- Uploaded Electrical Schematics of the robot.
- Uploaded PCB images and production file.

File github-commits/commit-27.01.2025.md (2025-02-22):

Commit - 27/01/2025

- Created the initial folder structure for the repository:
  - Added `3D-models/`, `electrical-schematics/`, `github-logs/`, `media/`, `other/`, and `src/` folders.
  - Inside `media/`, created subfolders: `robot-photos/`, `team-photos/`, and `video/`.
  - Added `README.md` files to all folders to describe their content and purpose:
    
- Uploaded current 3D models of the robot:
  - Added `.STL` files for robot chassis, drive base and steering components.
  - Files are located in the `3D-models/` folder.
 
- Uploaded current technical draws of the 3D Models:

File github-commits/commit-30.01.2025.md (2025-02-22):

Commit - 30/01/2025

- Uploaded first version of qualy code. The version that uses ultrasonic sensors.

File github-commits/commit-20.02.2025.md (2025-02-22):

Commit - 20/02/2025

- Created diverse tests for gyro, steering servo, motor etc.
- Updated camera.py

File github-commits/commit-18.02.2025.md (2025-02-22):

Commit - 18/02/2025

- Developed camera code even more.

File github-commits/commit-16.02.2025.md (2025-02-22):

Commit - 16/02/2025

- Uploaded camera support stl file.
- Updated steering wheel mounts and gear D axle for better power transfer.

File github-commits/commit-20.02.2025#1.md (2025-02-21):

Commit - 20/02/2025#1

- Created diverse tests for gyro, steering servo, motor etc.
- Updated camera.py

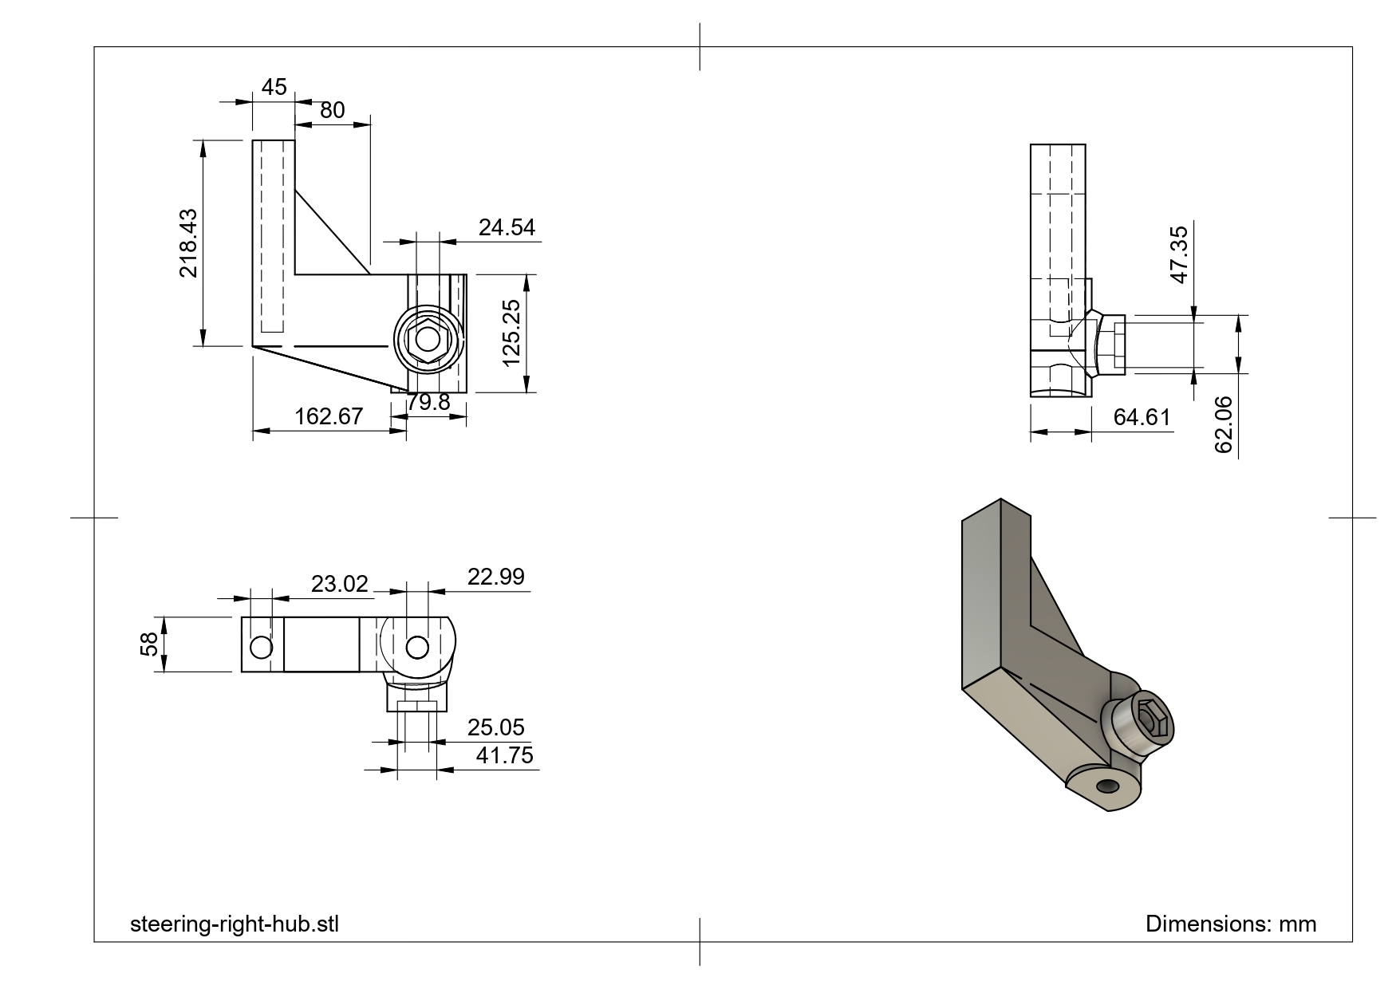
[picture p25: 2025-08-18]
technical-draws/steering-right-hub.jpg

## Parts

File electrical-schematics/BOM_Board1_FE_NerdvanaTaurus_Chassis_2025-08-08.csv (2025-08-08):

No. | Quantity | Comment | Designator | Footprint | Value | Manufacturer Part | Manufacturer | Supplier Part | Supplier
1 | 1 | KH-2.54PH180-1X2P-L11.5 | - + | HDR-TH_2P-P2.54-V-M |  | KH-2.54PH180-1X2P-L11.5 | kinghelm(金航标) | C2905434 | LCSC
2 | 2 | 220uF | C1,C2 | CAP-TH_BD6.3-P2.50-D1.0-FD | 220uF | KM221M025E110A | CapXon(丰宾) | C59416 | LCSC
3 | 1 | 220nF | C3 | C0805 | 220nF | 0805B104M250CT | Walsin(华新科) |  | LCSC
4 | 3 | 100nF | C4,C6,C8 | C0805 | 100nF | 0805B104M250CT | Walsin(华新科) | C163183 | LCSC
5 | 1 | 47uF | C5 | CAP-SMD_L3.2-W1.6-RD | 47uF | TC212A476K006Y | Sunlord(顺络) | C108525 | LCSC
6 | 2 | 2.54-1*2P母 | CameraData,CameraPower | HDR-TH_2P-P2.54-V-F |  | 2.54-1*2P母 | BOOMELE(博穆精密) | C49661 | LCSC
7 | 5 | HDR-F_2.54_1x3P | DistS1,DistS2,DistS3,DistS4,Servo | HDR-TH_3P-P2.54-V-F
8 | 1 | 2.54-1*6P母 | Encoder | HDR-TH_6P-P2.54-V-F |  | 2.54-1*6P母 | BOOMELE(博穆精密) | C40877 | LCSC
9 | 1 | 2.54-1*4P母 | Gyro | HDR-TH_4P-P2.54-V-F |  | 2.54-1*4P母 | BOOMELE(博穆精密) | C2718488 | LCSC
10 | 1 | IFX9201SGAUMA1_ | IFX_A1 | PG-DSO-12-17
11 | 4 | XL-1608UBC-04 | LED1,LED2,LED3,LED4 | LED0603-RD_RED |  | XL-1608UBC-04 | XINGLIGHT(成兴光) | C965807 | LCSC
12 | 1 | XL-1608SURC-06 | LED5 | LED0603-RD_RED |  | XL-1608SURC-06 | XINGLIGHT(成兴光) | C965799 | LCSC
13 | 1 | MST-12D18G4 SPDT Slide Switch | ON/OFF | SW-SMD_MST-12D18G4-SPDT-SLIDE-SWITCH |  | MST-12D18G4 SPDT Slide Switch | SHOU HAN(首韩) | C49023767 | LCSC
14 | 1 | IRFR3411TR-VB | Q1 | TO-252-2_L6.6-W6.1-P4.57-LS9.9-BR-CW |  | IRFR3411TR-VB | VBsemi(微碧半导体) | C879037 | LCSC
15 | 4 | 470Ω | R4,R5,R6,R7 | R0603 | 470Ω | 0603WAF4700T5E | UNI-ROYAL | C23179 | LCSC
16 | 1 | 10kΩ | R8 | R0603 | 10kΩ | RC0603FR-071KL | YAGEO(国巨) |  | LCSC
17 | 1 | 200Ω | R9 | R0603 | 200Ω | RC0603FR-071KL | YAGEO(国巨) |  | LCSC
18 | 1 | 1kΩ | R10 | R0603 | 1kΩ | RC0603FR-071KL | YAGEO(国巨) | C22548 | LCSC
19 | 2 | B3U-1000P | RST,START | KEY-SMD_B3U-1000PM |  | B3U-1000P | OMRON(欧姆龙) | C231329 | LCSC
20 | 1 | ARDUINO_NANO | U4 | COMM-TH_ARDUINO_NANO |  | ARDUINO_NANO |  | C9900017879 | LCSC
21 | 1 | 78M05 | U5 | TO-252-2_L6.5-W6.1-P4.58-LS10.0-TL |  | 78M05 | SHIKUES(时科) | C111265 | LCSC

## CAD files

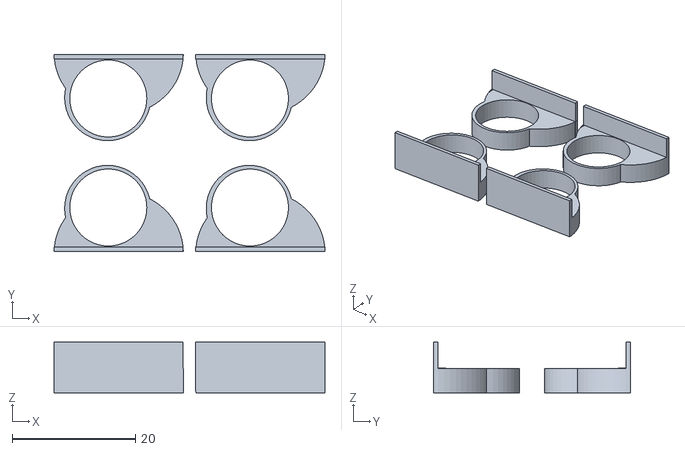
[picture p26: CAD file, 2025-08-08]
3D-models/back-rings-for-differential-to-wheel-axles.stl
44.0 x 32.0 x 8.24

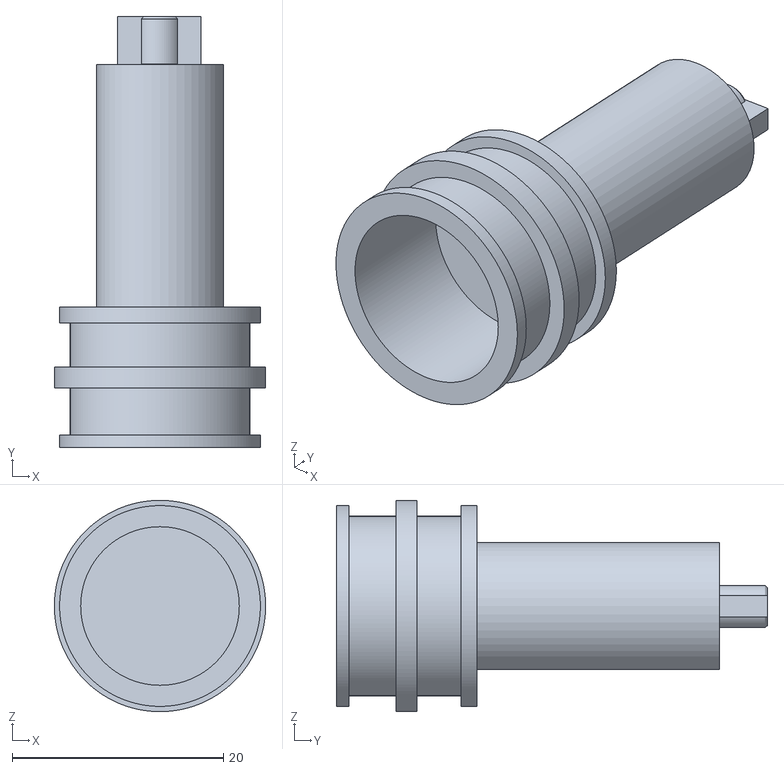
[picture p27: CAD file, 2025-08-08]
3D-models/back-wheel.stl
20.0 x 40.8 x 20.0

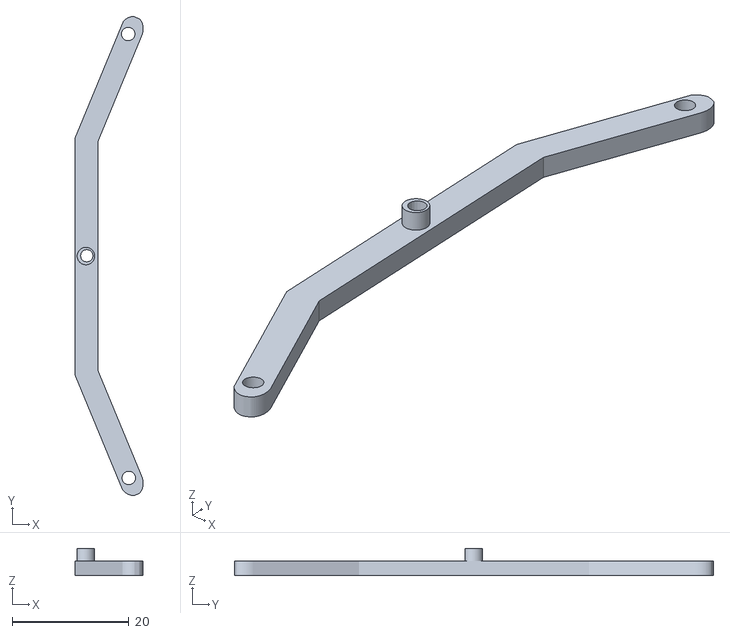
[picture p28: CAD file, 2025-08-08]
3D-models/servo-to-wheel-hub-fixed-bar.stl
11.7 x 82.1 x 4.70

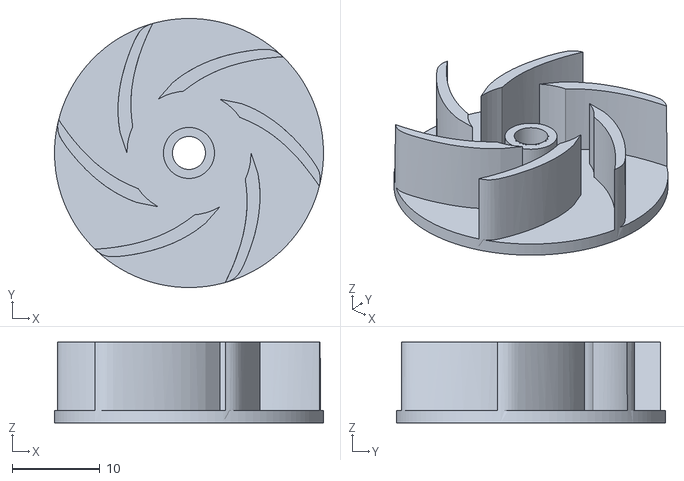
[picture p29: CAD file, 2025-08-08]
3D-models/impeller-fan.stl
30.6 x 30.6 x 9.20

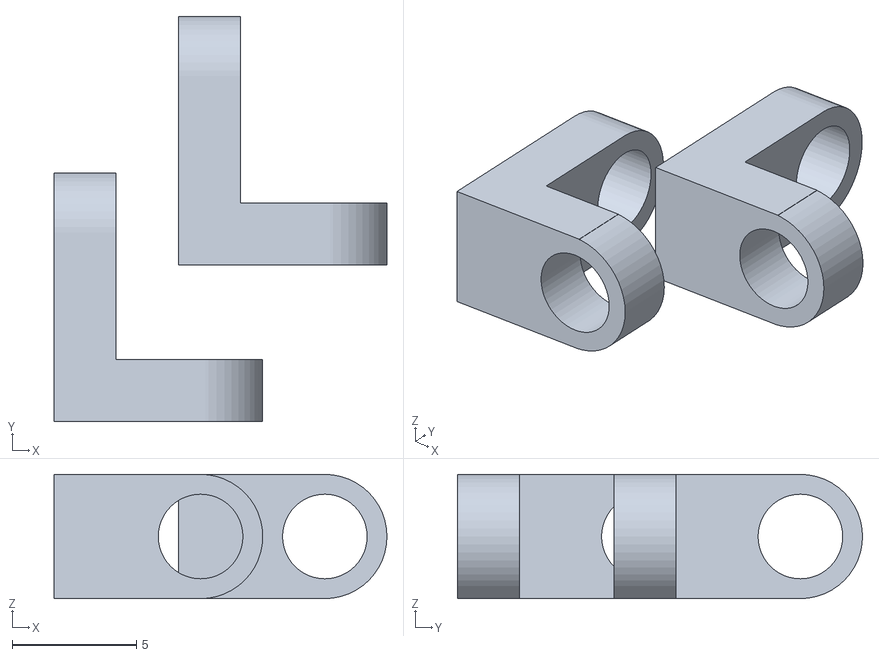
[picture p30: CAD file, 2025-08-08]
3D-models/openmv-camera-mounts.stl
13.4 x 16.3 x 5.00

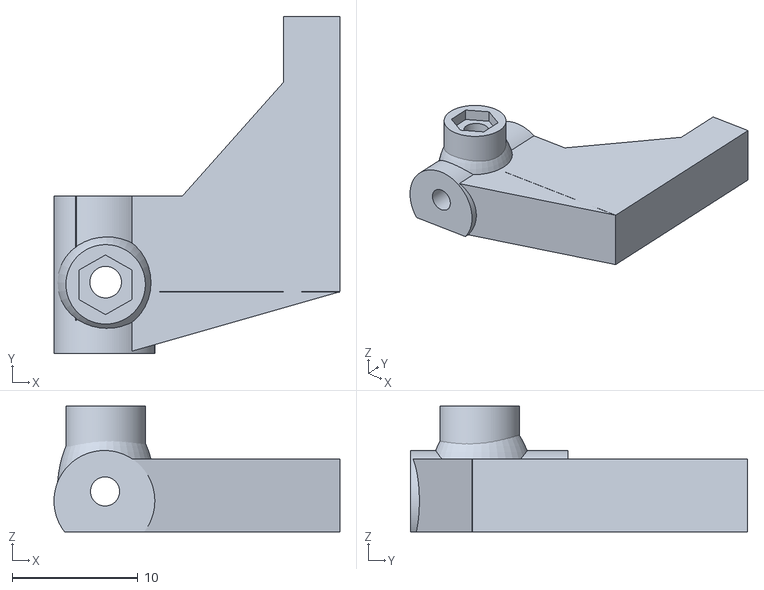
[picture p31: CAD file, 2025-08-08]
3D-models/steering-left-hub.stl
22.7 x 26.8 x 10.0

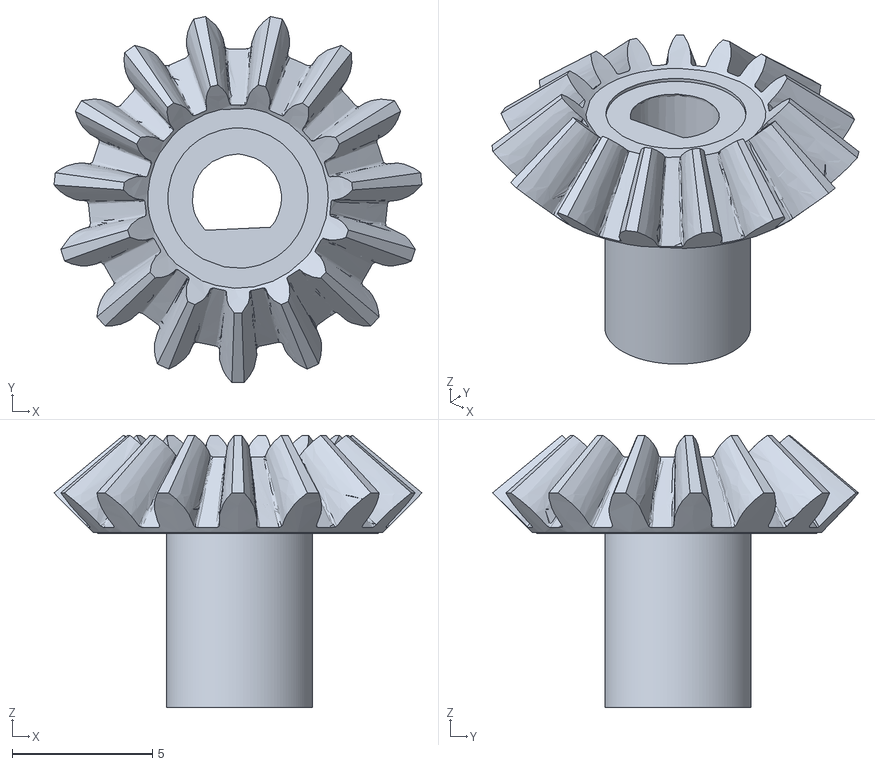
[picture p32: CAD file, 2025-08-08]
3D-models/pinion-differential.stl
13.1 x 13.0 x 9.70

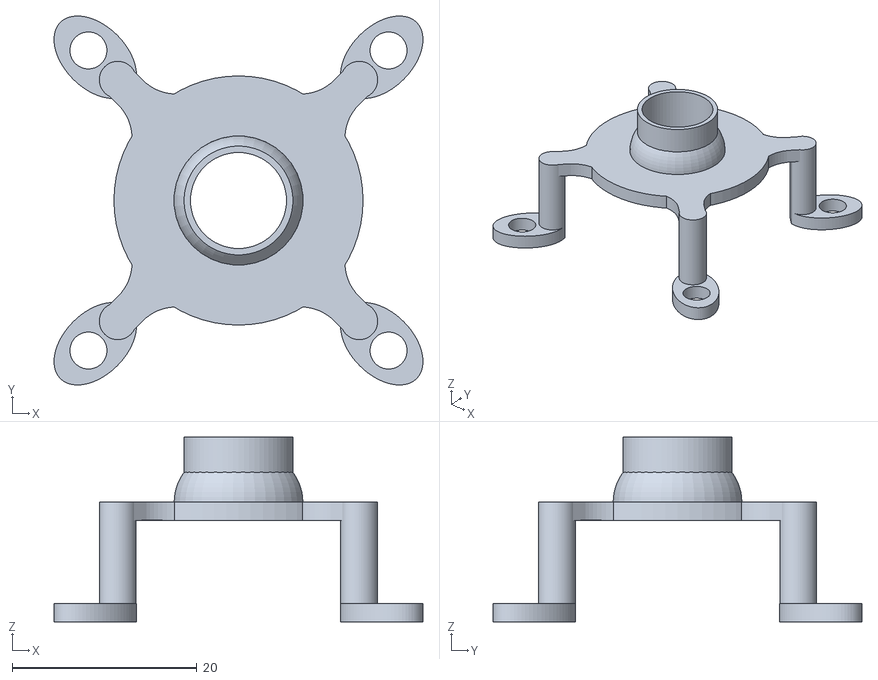
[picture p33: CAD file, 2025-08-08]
3D-models/impeller-base.stl
40.0 x 40.0 x 20.0

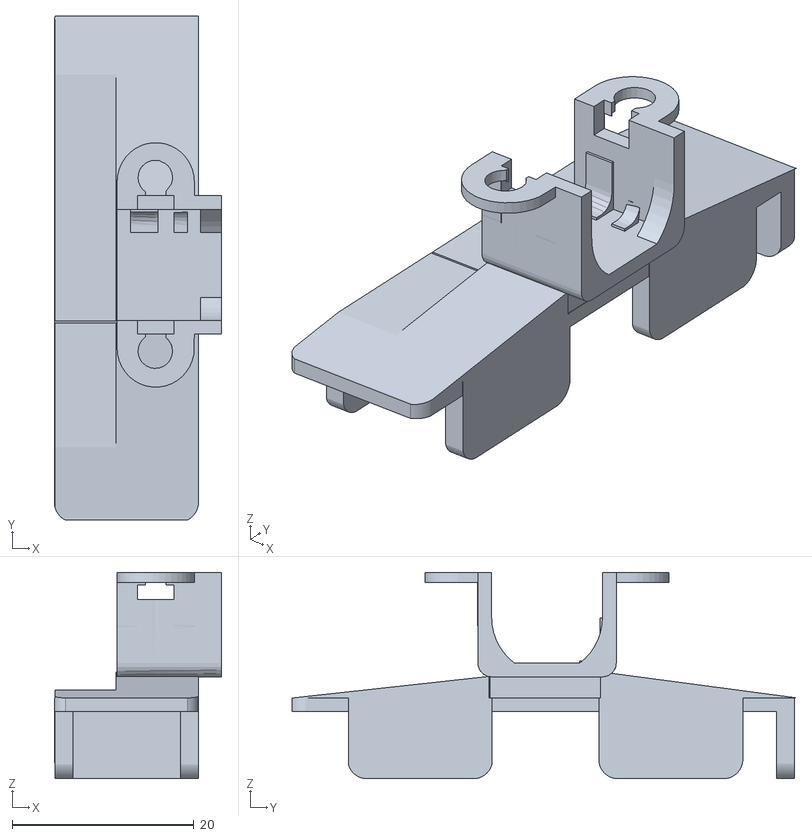
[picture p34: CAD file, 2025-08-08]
3D-models/drive-motor-support-with-battery.stl
18.4 x 55.5 x 22.7

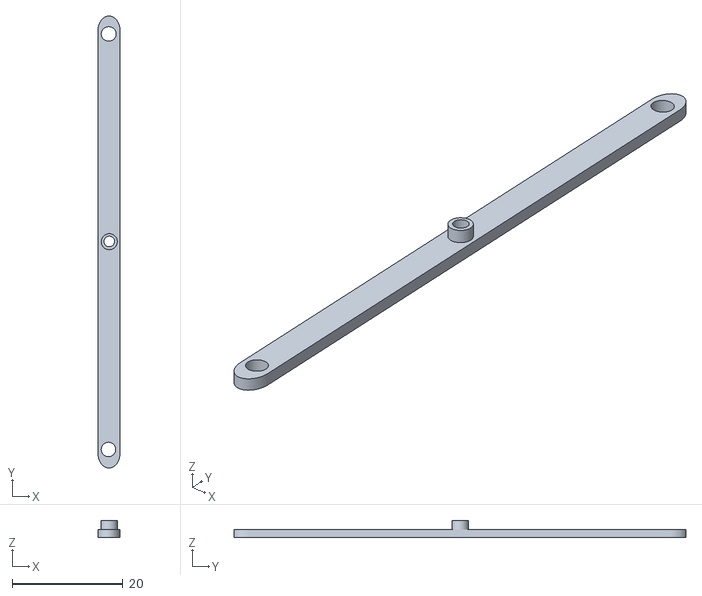
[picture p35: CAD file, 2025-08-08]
3D-models/steering-servo-to-hub-bar.stl
4.00 x 81.5 x 3.10

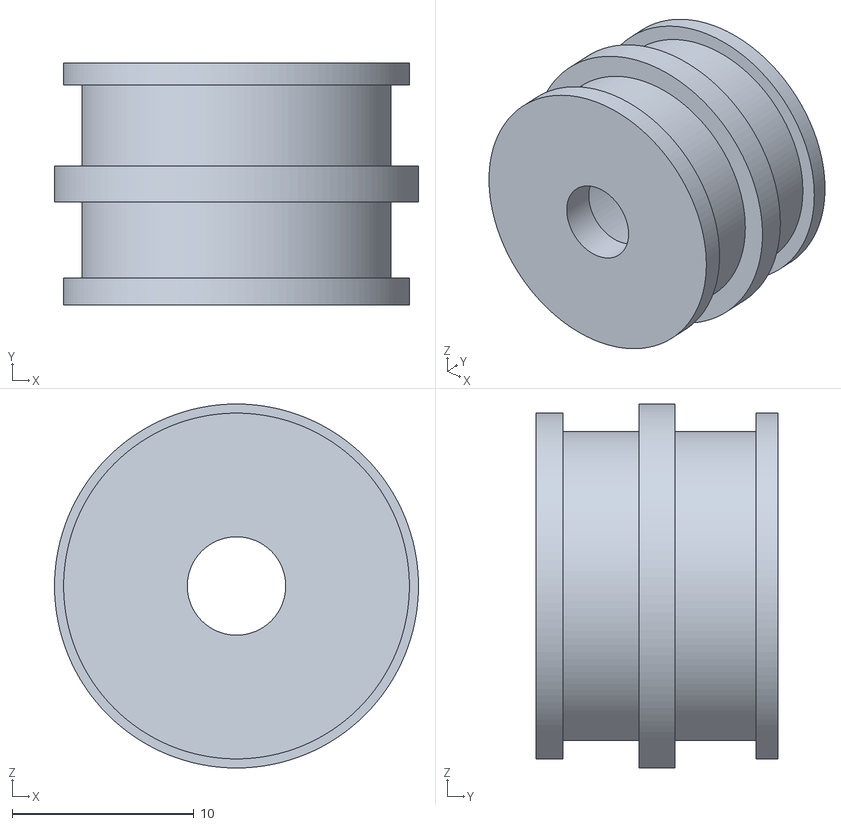
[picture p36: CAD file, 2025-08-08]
3D-models/front-wheel.stl
20.0 x 13.3 x 20.0

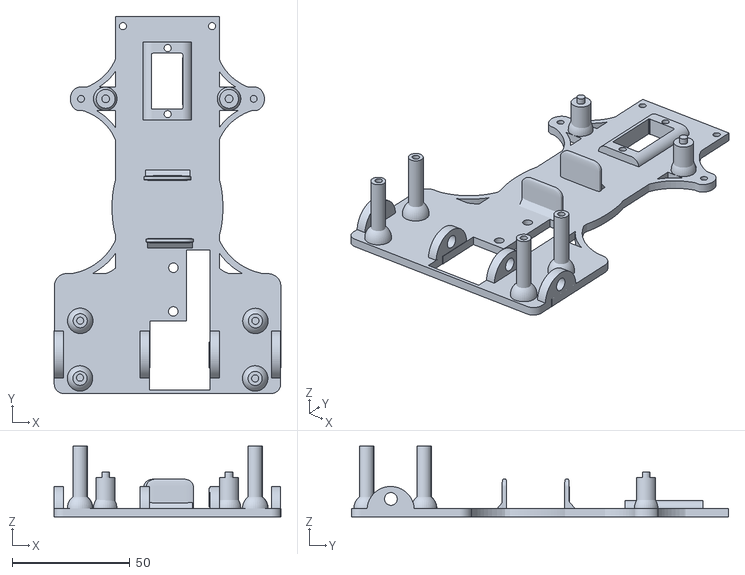
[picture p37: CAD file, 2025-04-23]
3D-models/chassisV5.stl
96.0 x 159.8 x 30.0

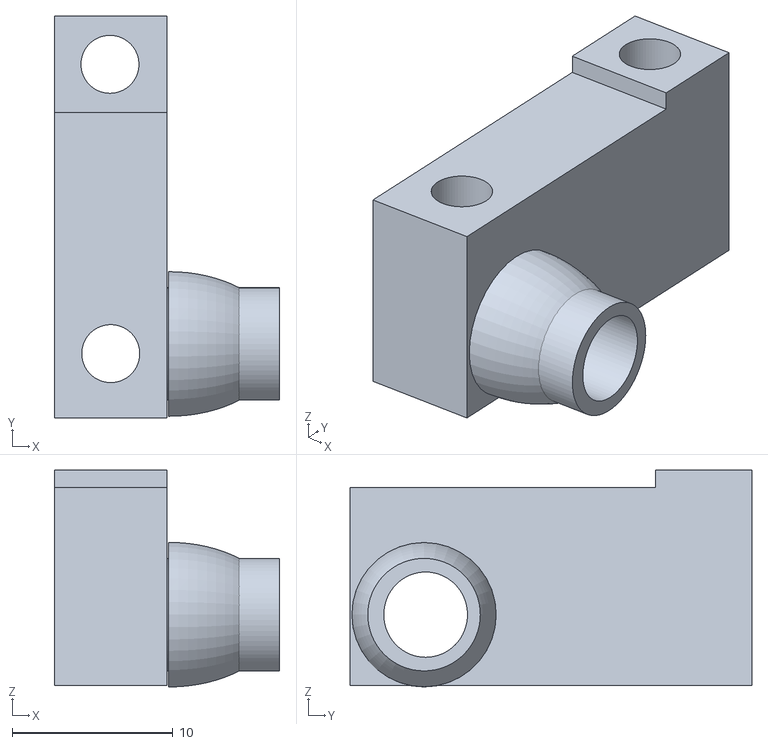
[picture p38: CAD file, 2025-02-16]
3D-models/wheel-mount-rightV2.stl
14.0 x 25.0 x 13.5

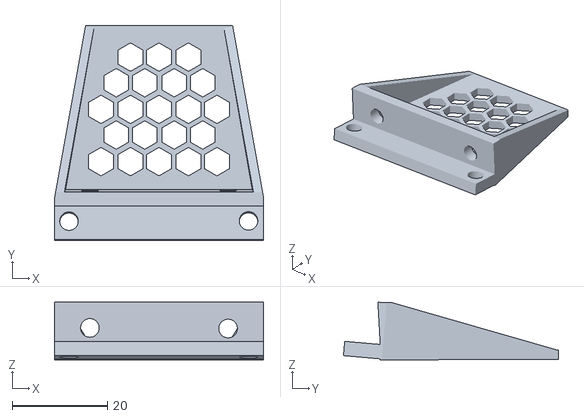
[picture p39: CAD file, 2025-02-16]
3D-models/openmv-camera-mountV2.stl
44.0 x 45.3 x 12.1

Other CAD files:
3D-models/steering-right-hub.stl
3D-models/wheel-mount-leftV2.stl
3D-models/steering-connect-bar.stl
3D-models/steering-left-small-bar.stl
3D-models/chassisV2.stl
3D-models/chassisV3.stl
3D-models/chassisV4.stl
3D-models/gear-Daxle.stl
3D-models/openmv-camera-mount.stl
3D-models/steering-right-small-bar.stl
3D-models/wheel-mount-left.stl
3D-models/wheel-mount-right.stl

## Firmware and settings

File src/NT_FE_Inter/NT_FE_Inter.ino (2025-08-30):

#include <Wire.h>
#include <math.h>
#include <ESP32Encoder.h>
#include <ESP32Servo.h>
#include <SoftwareSerial.h>
#include "BMI088.h"

#define RUN_MODE 1  // 0 - Open Round, 1 - Cubes Round

// ================ Pin Definitions ================
#define PWMA D7
#define DIRA D8

#define PWM_IMPELLER D9

#define START_BTN D10

#define P4 D0
#define P5 D1

#define DEBUG_LED1 D6
#define DEBUG_LED2 D3

#define PWM_DIST_FRONT A0
#define PWM_DIST_BACK A2
#define PWM_DIST_LEFT A3
#define PWM_DIST_RIGHT A1

// ======= Distance sensor direction enum =======
enum DistanceDir : uint8_t { FRONT_DIR,
                             LEFT_DIR,
                             RIGHT_DIR,
                             BACK_DIR };


// ================ Speed Control ================
int robot_speed = 56;  // 57 - 59 // 100
int exit_speed = 56;
int park_speed = 58;
int impeller_speed = 0;
int cube_last = 1;

// === Encoder pins ===
#define ENCODER_A D5
#define ENCODER_B D4
volatile int32_t encoder_ticks = 0;

#define PPR 12.0f  // 12 pulses per rev, single-edge
#define QUAD_EDGES (PPR * 4.0f)
#define GEAR_RATIO 1.0f
#define WHEEL_DIAM 29.0f  // mm
#define MM_PER_TICK 1.18f

// ================ Motors and PID ================3
double current_angle_gyro = 0.0;  // steering asymmetry
double kp = 0.038;                // 0.044
double ki = 0;
double kd = 0.061;  // 0.082
double pid_error = 0, pid_last_error = 0;

// Integration & drift
double gyro_last_read_time = 0; 
double drifts_z = 0;  // drift in °/s
double gz = 0;        // integrated angle in degrees


#define PWM_MOTOR_CHANNEL 5
#define PWM_MOTOR_FREQ 1000
#define PWM_MOTOR_RESOLUTION 8

#define PWM_IMPELLER_CHANNEL 4
#define PWM_IMPELLER_FREQ 1000
#define PWM_IMPELLER_RESOLUTION 8


#define STEERING_SERVO D2
Servo steeringServo;
#define STEERING_LEFT 135
#define STEERING_CENTER 85
#define STEERING_RIGHT 35

#define CORRECTION_ANGLE 35

#define FOLLOW_CUBE_DEAD_TIME 250

// ================ UART Communication ================
#define RX_PIN D0
#define TX_PIN D1
SoftwareSerial cameraSerial(RX_PIN, TX_PIN);
String receivedMessage = "";
String command = "";
String current_color = "";

// ================ Turns count and direction ================
int turn_direction = 0;
int turn_count = 0;
const int max_turns = 12;
unsigned long lastTurnTime = 0, lastLineDetectedTime = 0;

long last_follow_cube = 0;


// ================ Avoid Cubes Variables ================
float follow_cube_angle = 0;  // PID steering correction for cube following.

unsigned long last_cube_time = 0;  // remember when we last avoided one


// ================ Robot States ================
enum RobotState {
  PID,
  FOLLOW_CUBE,
  AVOID_CUBE,
  AFTER_CUBE,
  PARK
};

RobotState currentState = PID;
char cube_avoid_direction = 'R';  // 'R' for red cube avoidance, 'L' for green cube avoidance
float desiredSteering = 0.0;
 
// ================ Debug Mode ================
bool debug = false;
bool debuggyro = false;
bool debugcam = false;
bool firstcube = false;


void setup() {

  //debug_distance_infinite(LEFT_DIR);

  steering_servo_setup();
  motor_driver_setup();
  impeller_setup();

  pinMode(LED_BUILTIN, OUTPUT);
  pinMode(DEBUG_LED1, OUTPUT);
  pinMode(DEBUG_LED2, OUTPUT);

  pinMode(PWM_DIST_LEFT, INPUT);
  pinMode(PWM_DIST_RIGHT, INPUT);
  pinMode(PWM_DIST_FRONT, INPUT);
  pinMode(PWM_DIST_BACK, INPUT);


  encoder_setup();

  Serial.begin(115200);

  cameraSerial.begin(19200);
  while (!cameraSerial)
    ;
  blink_led(DEBUG_LED1, 200);

  gyro_setup();
  blink_led(DEBUG_LED2, 200);

  digitalWrite(DEBUG_LED2, HIGH);
  pinMode(START_BTN, INPUT_PULLUP);

  while (digitalRead(START_BTN) == 1) {
    move(0);
    flush_messages();
  }

  //move_gyro_until_side_detect_cycle(LEFT_DIR, park_speed, current_angle_gyro);

  setImpeller(impeller_speed);
  delay(500);

  digitalWrite(DEBUG_LED1, HIGH);
  custom_delay(500);

  // Start from parking
  if (RUN_MODE == 1) {
    if (readDistanceMM(LEFT_DIR) > readDistanceMM(RIGHT_DIR)) {  // exit right/.
      move_until_angle_max(exit_speed, 75);

      move(65);
      delay(100);

      turn_direction = 1;
      move_until_angle_max(exit_speed, 0);

      move_straight_on_gyro(-robot_speed, 1400);
    } else {  // exit left
      move_until_angle_max(exit_speed, -70);

      move(65);
      delay(100);

      turn_direction = -1;

      move_until_angle_max(exit_speed, 0);

      move_straight_on_gyro(-robot_speed, 1800);
    }
  }
}

void loop() {

  // 1) Max‐turns timeout
  if (turn_count >= max_turns || current_angle_gyro == 1080) {
    if (RUN_MODE == 1) {
      currentState = PARK;
    } else {
      unsigned long t0 = millis();
      while (millis() - t0 < 1400) {
        read_gyro_data();
        double error = current_angle_gyro - gz;
        pid_error = error * kp + (pid_error - pid_last_error) * kd;
        pid_last_error = pid_error;
        steer(pid_error);
        move(robot_speed);
      }
      stop_motor();
      if (debug) Serial.println("Maximum turns reached. Stopping...");
      while (true)
        ;
    }
  }

  // 2) Fresh gyro read and flush camera
  read_gyro_data();

  // 3) State‐machine drive logic
  switch (currentState) {

    case PID:
      {
        // PID straight‐drive
        double err = current_angle_gyro - gz;
        pid_error = (err)*kp + (pid_error - pid_last_error) * kd;
        pid_last_error = pid_error;
        steer(pid_error);
        move(robot_speed);
        break;
      }

    case FOLLOW_CUBE:
      {
        if (millis() - last_follow_cube > FOLLOW_CUBE_DEAD_TIME) {
          currentState = PID;
        }
        // steer toward cube
        steer(follow_cube_angle);
        move(robot_speed);
        break;
      }

    case AVOID_CUBE:
      {
        // avoidance maneuver
        pass_cube(cube_avoid_direction);
        break;
      }

    case AFTER_CUBE:
      {
        int angle_addition = (cube_last == 1) ? 0 : 0;
        double err = current_angle_gyro - gz + cube_last * (CORRECTION_ANGLE + angle_addition);
        if (abs(err) < 5) {
          if (-cube_last == turn_direction) {
            move_cm(5, robot_speed, current_angle_gyro + -1 * cube_last * (CORRECTION_ANGLE + angle_addition));
          } else {
            move_cm(5, robot_speed, current_angle_gyro + -1 * cube_last * (CORRECTION_ANGLE + angle_addition));
          }
          currentState = PID;
        } else {
          pid_error = (err)*kp + (pid_error - pid_last_error) * kd;
          pid_last_error = pid_error;
          steer(pid_error);
        }
        move(robot_speed);
        //flush_messages();
        break;
      }

    case PARK:
      {
        // in functions.ino
        break;
      }
  }

  // 4) Read & dispatch any new OpenMV commands
  while (cameraSerial.available() > 0) {
    char c = cameraSerial.read();
    if (c == '\n') {
      // Normalize & execute
      receivedMessage.trim();
      receivedMessage.toUpperCase();
      execute_command(receivedMessage);
      receivedMessage = "";
      flush_messages();
    } else {
      receivedMessage += c;
    }
  }

  //Serial.println(currentState);
}

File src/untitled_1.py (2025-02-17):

import sensor, time
from pyb import UART, LED

# **Initialize Camera**
sensor.reset()
sensor.set_pixformat(sensor.RGB565)
sensor.set_framesize(sensor.QVGA)
sensor.set_vflip(True)
sensor.set_hmirror(True)
sensor.skip_frames(time=2000)

# **Disable auto settings for stable color tracking**
sensor.set_auto_gain(False)
sensor.set_auto_whitebal(False)
sensor.set_auto_exposure(False, exposure_us=8000)  # Adjusted exposure for better visibility
clock = time.clock()

# **Setup UART Communication**
uart = UART(3, 19200)

# **Setup LEDs**
red_led = LED(1)
green_led = LED(2)
blue_led = LED(3)

# **Color Thresholds (LAB Space)**
red_threshold = [(18, 80, 5, 60, -10, 65)]
green_threshold = [(20, 85, -60, -5, -5, 55)]
blue_threshold = [(10, 80, -5, 25, -50, -5)]
orange_threshold = [(30, 80, 5, 45, 15, 75)]

# **Define Regions of Interest (ROI)**
image_height = sensor.height()
cubes_roi = (10, int(image_height * 0.6), sensor.width() - 20, int(image_height * 0.4))  # Bottom 40%
lines_roi = (5, int(image_height * 0.6), sensor.width() - 10, int(image_height * 0.4))  # Bottom 40%

# **Blob Filtering Parameters**
min_cube_size = 30  # Lowered to capture full objects
min_line_size = 80  # Lowered to detect thinner lines
min_area = 10       # Ignore objects with area < 10

def get_largest_blob(blobs):
    """Returns the largest blob in a list or None if empty."""
    return max(blobs, key=lambda b: b.area(), default=None)

def is_elongated(blob):
    """Check if the blob is at least 5 times taller than its width."""
    return blob.w() >= 5 * blob.h()

def is_invalid_orange(orange_blob, red_blobs):
    if orange_blob.h() > orange_blob.w():
        return "ignore_orange"  # Ignore if taller than wide

    for red_blob in red_blobs:
        if (
            red_blob.x() < orange_blob.x() + orange_blob.w() and
            red_blob.x() + red_blob.w() > orange_blob.x() and
            red_blob.y() < orange_blob.y() + orange_blob.h() and
            red_blob.y() + red_blob.h() > orange_blob.y()
        ):
            red_area = red_blob.area()
            orange_area = orange_blob.area()

            if red_area >= orange_area * 1.5:  # 50% larger or more
                return "ignore_orange"
            elif orange_area >= red_area * 1.5:  # 50% larger or more
                return "ignore_red"
            else:
                return None

    return None  # No overlap, keep both


direction = 0

while True:
    img = sensor.snapshot()

    # **Detect Red & Green Cubes**
    red_blobs = img.find_blobs(red_threshold, roi=cubes_roi, pixels_threshold=min_cube_size, area_threshold=min_cube_size, merge=True)
    green_blobs = img.find_blobs(green_threshold, roi=cubes_roi, pixels_threshold=min_cube_size, area_threshold=min_cube_size, merge=True)

    # **Detect Blue & Orange Lines**
    blue_blobs = img.find_blobs(blue_threshold, roi=lines_roi, pixels_threshold=min_line_size, area_threshold=min_line_size, merge=True)
    orange_blobs = img.find_blobs(orange_threshold, roi=lines_roi, pixels_threshold=min_line_size, area_threshold=min_line_size, merge=True)

    # **Find Largest Objects**
    red_cube = get_largest_blob([b for b in red_blobs if b.area() >= min_area])
    green_cube = get_largest_blob([b for b in green_blobs if b.area() >= min_area])
    blue_line = get_largest_blob([b for b in blue_blobs if b.area() >= min_area])
    orange_line = get_largest_blob([b for b in orange_blobs if b.area() >= min_area])

    # **Process Red Cube (Ignore if elongated or too small)**
    if red_cube and not is_elongated(red_cube):
        img.draw_rectangle(red_cube.rect(), color=(255, 0, 0))
        img.draw_cross(red_cube.cx(), red_cube.cy(), color=(255, 0, 0))
        img.draw_string(red_cube.x(), red_cube.y() + red_cube.h() - 10, str(red_cube.area()), color=(255, 0, 0))
        uart.write("RED Cube Detected at X:{} Y:{} Area:{}\n".format(red_cube.cx(), red_cube.cy(), red_cube.area()))

    # **Process Green Cube (Ignore if elongated or too small)**
    if green_cube and not is_elongated(green_cube):
        img.draw_rectangle(green_cube.rect(), color=(0, 255, 0))
        img.draw_cross(green_cube.cx(), green_cube.cy(), color=(0, 255, 0))
        img.draw_string(green_cube.x(), green_cube.y() + green_cube.h() - 10, str(green_cube.area()), color=(0, 255, 0))
        uart.write("GREEN Cube Detected at X:{} Y:{} Area:{}\n".format(green_cube.cx(), green_cube.cy(), green_cube.area()))

    # **Process Blue Line (Ignore if too small)**
    if blue_line:
        img.draw_rectangle(blue_line.rect(), color=(0, 0, 255))
        img.draw_string(blue_line.x(), blue_line.y() + blue_line.h() - 10, str(blue_line.area()), color=(0, 0, 255))
        uart.write("BLUE Line Detected at X:{} Width:{} Area:{}\n".format(blue_line.cx(), blue_line.w(), blue_line.area()))

    # **Process Orange Line (Ignore if invalid or too small)**
    if orange_line and not is_invalid_orange(orange_line, red_blobs):
        img.draw_rectangle(orange_line.rect(), color=(255, 165, 0))  # Orange color
        img.draw_string(orange_line.x(), orange_line.y() + orange_line.h() - 10, str(orange_line.area()), color=(255, 165, 0))
        uart.write("ORANGE Line Detected at X:{} Width:{} Area:{}\n".format(orange_line.cx(), orange_line.w(), orange_line.area()))

    # **Determine Direction Based on First Detected Line**
    if direction == 0:
        if orange_line and not is_invalid_orange(orange_line, red_blobs):
            direction = 2  # Orange line first → turn right
        elif blue_line:
            direction = 1  # Blue line first → turn left

    # **Send Direction Command to Arduino**
    uart.write(str(direction) + '\n')

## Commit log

2025-02-18 Update and rename untitled_1.py to camera.py
2025-08-18 Rename steering (2).gif to steering.gif
